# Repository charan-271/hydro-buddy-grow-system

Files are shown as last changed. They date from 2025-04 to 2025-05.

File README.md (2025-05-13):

# HydroBuddy Grow System

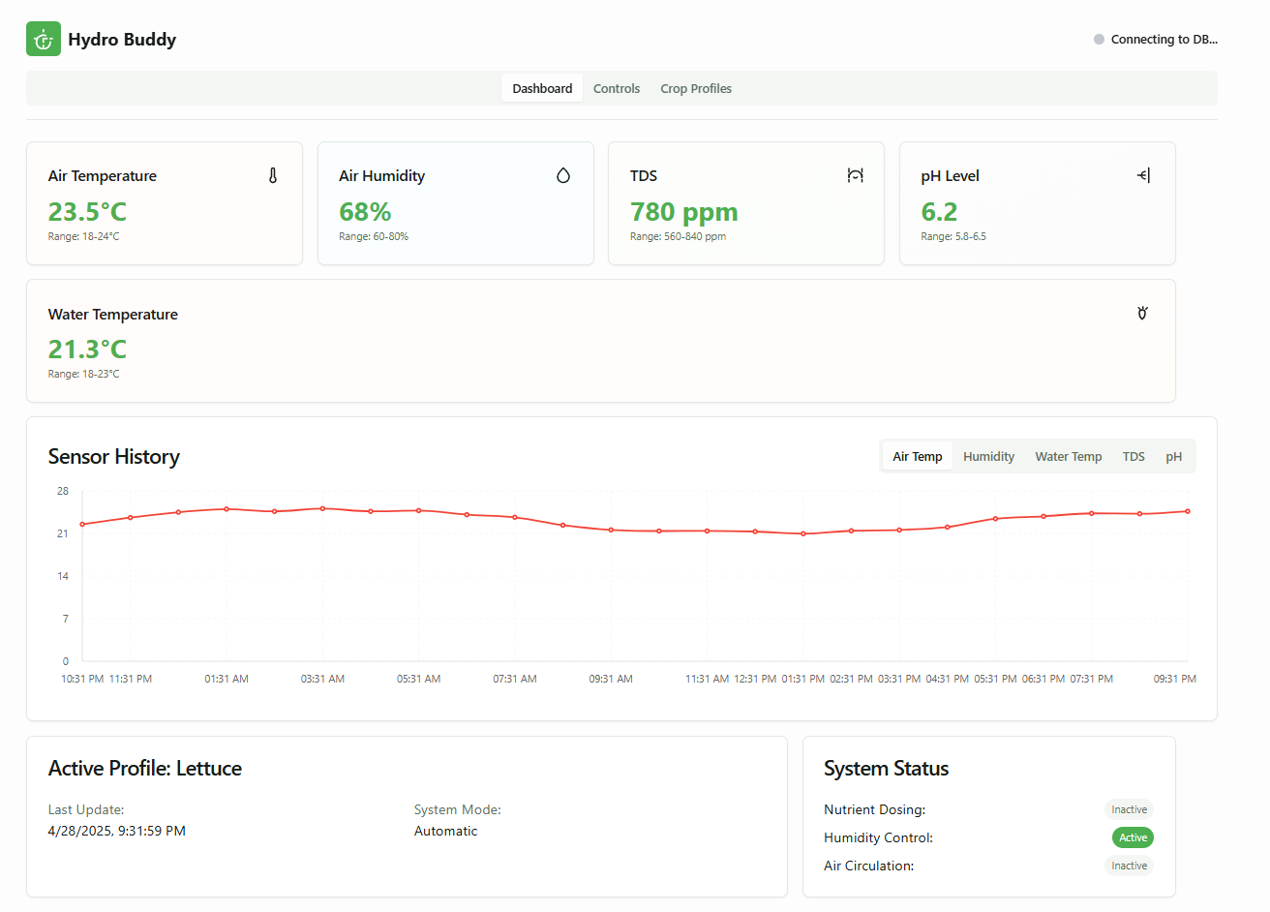
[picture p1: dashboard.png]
HydroBuddy Dashboard

*Dashboard view showing real-time sensor readings, historical data chart, and system status with relay indicators.*

HydroBuddy is a smart hydroponics monitoring and control system that helps you grow plants efficiently using IoT technology. It combines hardware sensors with a web-based dashboard to automate and monitor your hydroponic setup.

## What It Does

HydroBuddy continuously monitors key parameters for hydroponics:
- Water and air temperature
- Water pH level
- TDS (Total Dissolved Solids) for nutrient concentration
- Air humidity

The system provides:
- Real-time sensor readings
- Automated control based on crop profiles
- Historical data visualization
- Remote monitoring via web dashboard

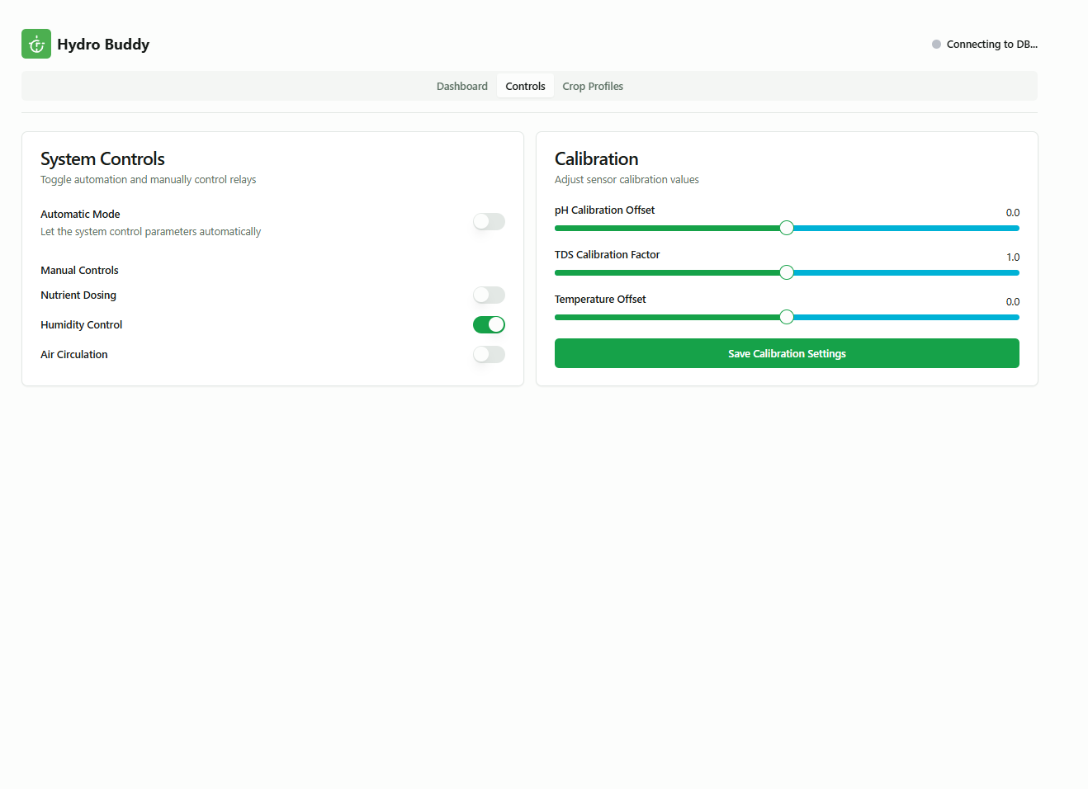
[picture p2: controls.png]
System Controls

*Control panel interface with manual relay controls, auto mode toggle, and sensor calibration settings.*

## Hardware Components

### Sensors
- DS18B20 waterproof temperature sensor (water temperature)
- DHT11 sensor (air temperature and humidity)
- Analog pH sensor with BNC connector
- TDS (EC) sensor for nutrient concentration

### Control Hardware
- ESP32 microcontroller (main board)
- BC547 transistors for relay control
- 5V relay modules for controlling pumps/fans
- Power supply (5V/2A recommended)

### Optional Components
- Peristaltic pumps for nutrient dosing
- Cooling fans for temperature control
- Humidifier for humidity control

### 3D Printed Components
The system includes 3D printable enclosures found in the STL Files directory:
- `hydroponics_box.stl` - Main enclosure for electronics
- `hydroponics_lid.stl` - Protective lid for the enclosure

### Hardware Connections

#### ESP32 Pin Connections
| Component | ESP32 Pin | Notes |
|---|---|---|
| DS18B20 Temperature Sensor | GPIO 4 | Use a 4.7kΩ pull-up resistor between data and VCC |
| DHT11 Temp/Humidity Sensor | GPIO 2 | Use a 10kΩ pull-up resistor between data and VCC |
| pH Sensor (Analog) | GPIO 34 | Analog input only, no pull-up needed |
| TDS Sensor (Analog) | GPIO 35 | Analog input only, no pull-up needed |
| Relay 1 (Nutrient Pump) | GPIO 25 | Via BC547 transistor with 1kΩ base resistor |
| Relay 2 (pH Control) | GPIO 26 | Via BC547 transistor with 1kΩ base resistor |
| Relay 3 (Water Pump) | GPIO 27 | Via BC547 transistor with 1kΩ base resistor |
| Relay 4 (Fan/Cooling) | GPIO 14 | Via BC547 transistor with 1kΩ base resistor |

#### Power Connections
- ESP32: 5V from power supply or USB
- Sensors: 3.3V from ESP32 or regulated 3.3V supply
- Relays: 5V from external power supply (separate from ESP32 logic power)

#### Transistor Wiring (for each relay)
```
ESP32 GPIO Pin ---> 1kΩ Resistor ---> BC547 Base
                                       BC547 Emitter ---> GND
                                       BC547 Collector ---> Relay Control Pin
```

#### Sensor Wiring
- **DS18B20 Temperature Sensor**:
  - Red wire to 3.3V
  - Black wire to GND
  - Yellow/Data wire to GPIO 4 with 4.7kΩ pull-up resistor

- **DHT11 Temperature/Humidity Sensor**:
  - VCC to 3.3V
  - GND to GND
  - DATA to GPIO 2 with 10kΩ pull-up resistor

- **pH Sensor**:
  - BNC connector to pH probe
  - VCC to 5V
  - GND to GND
  - Analog Output to GPIO 34

- **TDS Sensor**:
  - VCC to 5V
  - GND to GND
  - Analog Output to GPIO 35

### Wiring Diagram Notes
- Keep sensor cables away from power lines to reduce interference
- Use shielded cables for pH and TDS sensors to improve accuracy
- Add 100μF capacitor between relay power supply and GND to reduce interference
- Connect all GND points to a common ground

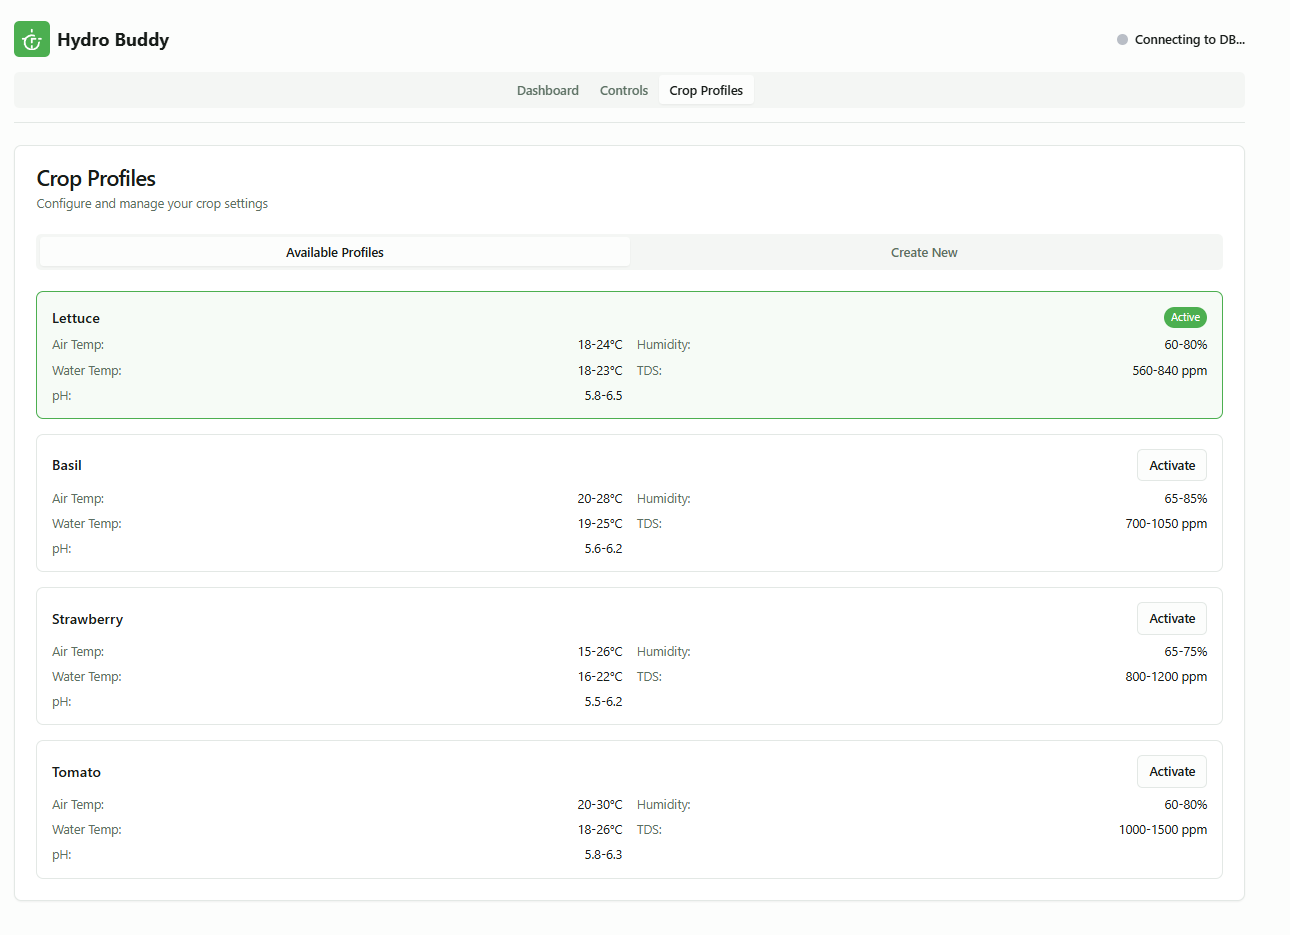
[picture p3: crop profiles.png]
Crop Profiles Management

*Crop profiles management interface showing parameter ranges for different crops and profile activation controls.*

## Software Components

### Microcontroller Code
- Arduino code for ESP32 (`hydroponics_final.ino`)
- Sensor data collection and processing
- WiFi connectivity and HTTP server
- Automatic control logic based on crop parameters

### Web Dashboard
- React TypeScript frontend
- Realtime sensor data visualization with interactive charts
- Crop profile management
- Responsive design for desktop/mobile access

### Backend
- Supabase for data storage and authentication
- RESTful API endpoints for sensor data
- Serverless functions for relay control and data processing
- Historical data retrieval and analysis

## Setting Up the Project

### Hardware Setup
1. Connect sensors to the ESP32 according to the pin definitions in `hydroponics_final/hydroponics_final.ino`
2. Connect the relay modules to the transistor control pins
3. Power the ESP32 and sensors with a 5V power supply
4. Optional: 3D print the enclosure using the STL files provided

### Software Setup
1. Clone the repository:
   ```
   git clone https://github.com/charan-271/hydro-buddy-grow-system.git
   cd hydro-buddy-grow-system
   ```

2. Install dependencies:
   ```
   bun install
   ```

3. Configure the ESP32:
   - Open `hydroponics_final/hydroponics_final.ino` in Arduino IDE
   - Set your WiFi credentials
   - Set the correct API endpoint for your Supabase instance
   - Upload to your ESP32

4. Configure the web dashboard:
   - Create a `.env` file with your Supabase credentials
   - Start the development server:
     ```
     bun run dev
     ```

5. Deploy Supabase functions:
   ```
   cd supabase
   supabase functions deploy
   ```

## Project Structure
The project follows a clean and modular structure:
- `/src/components` - React components for the dashboard
- `/src/hooks` - Custom React hooks for data and WebSocket handling
- `/src/integrations/supabase` - Supabase client configuration
- `/supabase/functions` - Serverless functions for relay and sensor data
- `/hydroponics_final` - Arduino code for the ESP32
- `/STL Files` - 3D printable enclosure designs

## Main Features

- **Real-time Monitoring**: View sensor data as it's collected
- **Historical Data**: Track plant growth conditions over time
- **Crop Profiles**: Preset configurations for different plant types
- **Automated Control**: Set-and-forget system that adjusts to optimal conditions
- **Mobile Responsive**: Monitor your system from anywhere

## Technologies Used

- **Frontend**: React, TypeScript, TailwindCSS, Shadcn UI
- **Backend**: Supabase (PostgreSQL database)
- **Hardware**: ESP32, Arduino libraries
- **Communication**: HTTP for API requests, WebSockets for realtime updates
- **Build Tools**: Vite, Bun

## Contributing

Contributions are welcome! Please feel free to submit a Pull Request.

## License

This project is open-source, available under the MIT License.

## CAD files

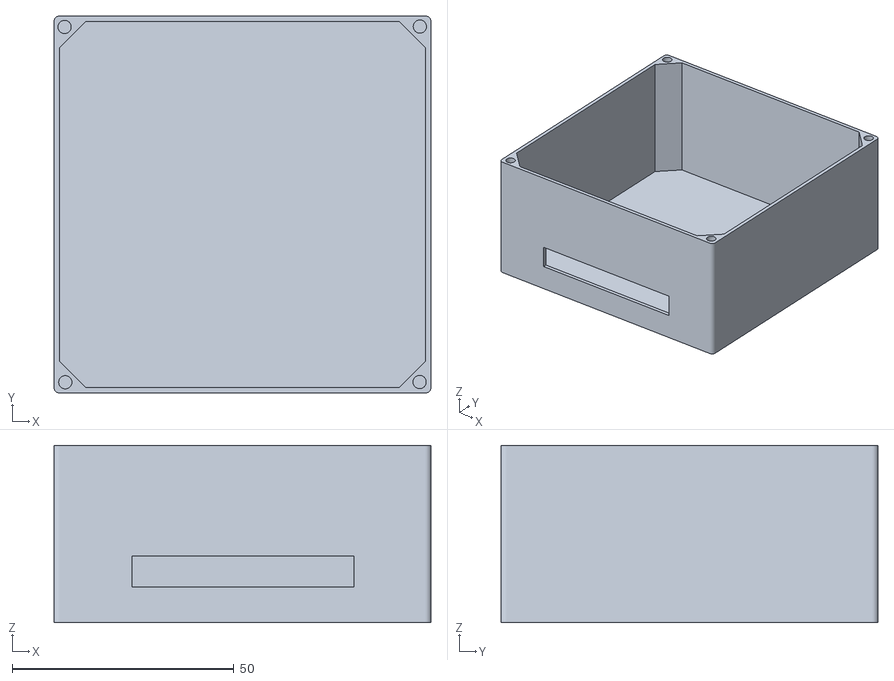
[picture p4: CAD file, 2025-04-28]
STL Files/hydroponics_box.stl
85.0 x 85.0 x 40.0

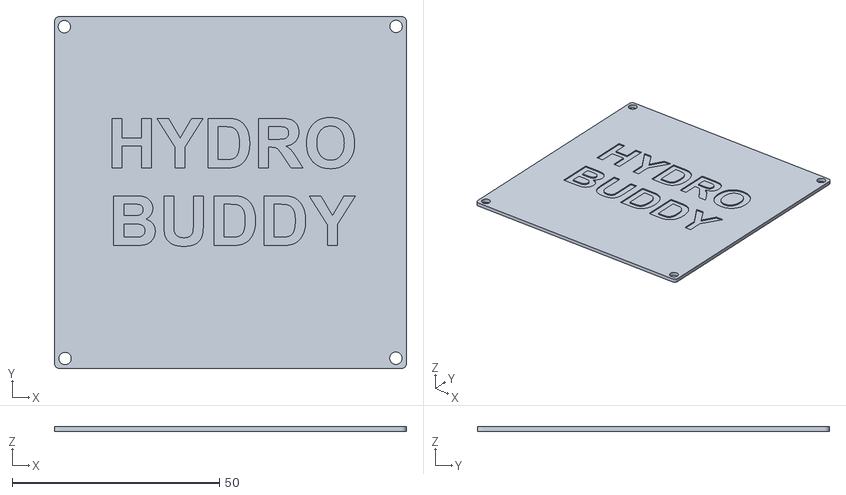
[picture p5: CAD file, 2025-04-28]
STL Files/hydroponics_lid.stl
85.0 x 85.0 x 1.20

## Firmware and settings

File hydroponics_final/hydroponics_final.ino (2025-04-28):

#include <WiFi.h>
#include <WebServer.h>
#include <HTTPClient.h>
#include <ArduinoJson.h>
#include <DHT.h>
#include <OneWire.h>
#include <DallasTemperature.h>

// WiFi Credentials
const char* ssid = "";
const char* password = "";

// Supabase Edge Function URL 
const char* serverUrl = "https://lstmfefngokizyxqpbdo.supabase.co/functions/v1/add-sensor-reading";

// Create Web Server on port 80
WebServer server(80);

// Pin Definitions
#define DHTPIN 4          // DHT11 data pin
#define DHTTYPE DHT11     // DHT 11
#define TDS_SENSOR_PIN 34 // Analog pin for TDS sensor
#define PH_SENSOR_PIN 32  // Analog pin for pH sensor
#define ONE_WIRE_BUS 22   // DS18B20 data pin (water temperature)

// Transistor Control Pins (BC547)
#define TRANSISTOR_WATER 17 // BC547 transistor for humidity control
#define TRANSISTOR_AIR 19   // BC547 transistor for air temperature control

// Sensor objects
DHT dht(DHTPIN, DHTTYPE);
OneWire oneWire(ONE_WIRE_BUS);
DallasTemperature waterTempSensor(&oneWire);

// Sensor calibration values
#define TDS_VREF 5.0      // Analog reference voltage
#define TDS_TEMPERATURE 25 // Reference temperature for TDS readings
float phCalibration = 0.0; // pH calibration offset

// Sensor Data Variables
float tdsValue = 0.0;
float pHValue = 0.0;
float humidity = 0.0;
float waterTemp = 0.0;
float airTemp = 0.0;

// Crop Configuration Structure
struct CropConfig {
  float min_tds = 0.0, max_tds = 0.0;
  float min_ph = 0.0, max_ph = 0.0;
  float min_humidity = 0.0, max_humidity = 0.0;
  float min_water_temp = 0.0, max_water_temp = 0.0;
  float min_air_temp = 0.0, max_air_temp = 0.0;
} cropConfig;

// Timing for non-blocking loop
unsigned long lastCheck = 0;
const unsigned long checkInterval = 10000; // 10 seconds
unsigned long lastSensorRead = 0;
const unsigned long sensorReadInterval = 2000; // 2 seconds
unsigned long lastDataUpload = 0;
const unsigned long dataUploadInterval = 10000; // 1 minute

// Utility: Check if cropConfig is actually configured
bool isCropConfigured() {
  return cropConfig.max_tds > 0.0 || cropConfig.max_ph > 0.0 ||
         cropConfig.max_humidity > 0.0 || cropConfig.max_water_temp > 0.0 ||
         cropConfig.max_air_temp > 0.0;
}

// Read TDS Sensor Value
float readTDSSensor() {
  // Read analog value and convert to voltage
  int analogValue = analogRead(TDS_SENSOR_PIN);
  float voltage = analogValue * (TDS_VREF / 4095.0); // ESP32 ADC is 12-bit (0-4095)
  
  // Temperature compensation
  float compensationCoefficient = 1.0 + 0.02 * (waterTemp - TDS_TEMPERATURE);
  float compensationVoltage = voltage / compensationCoefficient;
  
  // Convert voltage to TDS value
  float tdsValue = (133.42 * compensationVoltage * compensationVoltage * compensationVoltage 
                   - 255.86 * compensationVoltage * compensationVoltage 
                   + 857.39 * compensationVoltage) * 0.5;
  
  return tdsValue;
}

// Read pH Sensor Value
float readPHSensor() {
  // Get multiple samples for more accurate reading
  int samples = 10;
  float avgValue = 0;
  
  for(int i=0; i<samples; i++) {
    avgValue += analogRead(PH_SENSOR_PIN);
    delay(10);
  }
  
  avgValue = avgValue / samples;
  
  // Convert analog reading to voltage
  float voltage = avgValue * (3.3 / 4095.0); // ESP32 ADC is 12-bit (0-4095)
  float phValue = 3.5 * voltage + phCalibration;
  
  return phValue;
}

// Read all sensors
void readSensors() {
  // Read DHT11 (air temperature and humidity)
  humidity = dht.readHumidity();
  airTemp = dht.readTemperature();
  
  // Check if DHT reading failed
  if (isnan(humidity) || isnan(airTemp)) {
    Serial.println("❌ Failed to read from DHT sensor!");
    humidity = 0.0;
    airTemp = 0.0;
  }
  
  // Read DS18B20 water temperature
  waterTempSensor.requestTemperatures();
  waterTemp = waterTempSensor.getTempCByIndex(0);
  
  // Check if water temperature reading failed
  if (waterTemp == DEVICE_DISCONNECTED_C) {
    Serial.println("❌ Failed to read from DS18B20 sensor!");
    waterTemp = 0.0;
  }
  
  // Read TDS value
  tdsValue = readTDSSensor();
  
  // Read pH value
  pHValue = readPHSensor();
  
  // Log values
  Serial.println("📊 Sensor Readings:");
  Serial.print("TDS: "); Serial.print(tdsValue); Serial.println(" ppm");
  Serial.print("pH: "); Serial.println(pHValue);
  Serial.print("Humidity: "); Serial.print(humidity); Serial.println(" %");
  Serial.print("Water Temp: "); Serial.print(waterTemp); Serial.println(" °C");
  Serial.print("Air Temp: "); Serial.print(airTemp); Serial.println(" °C");
}

// Send sensor data to database via API
void sendSensorData() {
  if (WiFi.status() == WL_CONNECTED) {
    Serial.println("📤 Sending data to database...");
    HTTPClient http;
    
    // Create a JSON document
    StaticJsonDocument<200> doc;
    doc["air_temp"] = airTemp;
    doc["water_temp"] = waterTemp;
    doc["humidity"] = humidity;
    doc["ph"] = pHValue;
    doc["tds"] = tdsValue;
    
    String jsonString;
    serializeJson(doc, jsonString);
    
    // Begin HTTP POST request
    http.begin(serverUrl);
    http.addHeader("Content-Type", "application/json");
    
    // Send HTTP POST request
    int httpResponseCode = http.POST(jsonString);
    
    if (httpResponseCode > 0) {
      String response = http.getString();
      Serial.println("✅ HTTP Response code: " + String(httpResponseCode));
      Serial.println(response);
    } else {
      Serial.print("❌ Error code: ");
      Serial.println(httpResponseCode);
    }
    
    // Free resources
    http.end();
  } else {
    Serial.println("❌ WiFi disconnected. Cannot send data.");
  }
}

// Handle Root
void handleRoot() {
  server.send(200, "text/plain", "ESP32 Hydroponics System");
}

// Handle Update Crop Configuration
void handleUpdate() {
  if (server.hasArg("plain")) {
    String jsonData = server.arg("plain");
    Serial.println("✅ Data Received!");
    Serial.println(jsonData);

    StaticJsonDocument<512> doc;
    DeserializationError error = deserializeJson(doc, jsonData);

    if (error) {
      Serial.println("❌ JSON Parsing failed!");
      server.send(400, "application/json", "{\"error\":\"Invalid JSON!\"}");
      return;
    }

    // ✅ Store values properly
    cropConfig.min_tds = doc["min_tds"] | 0.0;
    cropConfig.max_tds = doc["max_tds"] | 0.0;
    cropConfig.min_ph = doc["min_ph"] | 0.0;
    cropConfig.max_ph = doc["max_ph"] | 0.0;
    cropConfig.min_humidity = doc["min_humidity"] | 0.0;
    cropConfig.max_humidity = doc["max_humidity"] | 0.0;
    cropConfig.min_water_temp = doc["min_water_temp"] | 0.0;
    cropConfig.max_water_temp = doc["max_water_temp"] | 0.0;
    cropConfig.min_air_temp = doc["min_atmosphere_temp"] | 0.0;
    cropConfig.max_air_temp = doc["max_atmosphere_temp"] | 0.0;

    Serial.println("✅ Crop configuration updated!");
    Serial.print("min_tds: "); Serial.println(cropConfig.min_tds);
    Serial.print("max_tds: "); Serial.println(cropConfig.max_tds);

    server.send(200, "application/json", "{\"message\":\"Configuration updated successfully!\"}");
  } else {
    server.send(400, "application/json", "{\"error\":\"Invalid data!\"}");
  }
}

// Handle Sensor Data Response
void handleSensorData() {
  server.sendHeader("Access-Control-Allow-Origin", "*");
  server.sendHeader("Access-Control-Allow-Methods", "GET, POST, OPTIONS");
  server.sendHeader("Access-Control-Allow-Headers", "Content-Type");
  
  // Create a proper JSON document
  StaticJsonDocument<256> doc;
  doc["status"] = "connected";
  doc["isConfigured"] = isCropConfigured();
  doc["TDS"] = tdsValue;
  doc["pH"] = pHValue;
  doc["Humidity"] = humidity;
  doc["WaterTemp"] = waterTemp;
  doc["AirTemp"] = airTemp;
  
  String jsonResponse;
  serializeJson(doc, jsonResponse);
  server.send(200, "application/json", jsonResponse);
}

// Optional Status Check Endpoint
void handleStatus() {
  String status = isCropConfigured() ? "✅ Crop data configured" : "⚠️ No crop data";
  server.send(200, "application/json", "{\"status\":\"" + status + "\"}");
}

// CORS handling
void handleOptions() {
  server.sendHeader("Access-Control-Allow-Origin", "*");
  server.sendHeader("Access-Control-Allow-Methods", "GET, POST, OPTIONS");
  server.sendHeader("Access-Control-Allow-Headers", "Content-Type");
  server.send(204);
}

// Control function for transistors
void controlTransistor(int pin, bool turnOn) {
  // For BC547 transistor, we send HIGH to turn ON and LOW to turn OFF
  // This is because the transistor conducts when base is HIGH
  digitalWrite(pin, turnOn ? HIGH : LOW);
  
  // Log the action
  Serial.print("Transistor on pin ");
  Serial.print(pin);
  Serial.println(turnOn ? " turned ON" : " turned OFF");
}

// Core Logic to Check Ranges
void checkAndControl() {
  if (!isCropConfigured()) {
    Serial.println("⚠️ No crop data configured!");
    return;
  }

  Serial.println("✅ Running automated control checks");

  if (tdsValue > cropConfig.max_tds) {
    Serial.println("⚠️ TDS out of range!");
  } else {
    Serial.println("✅ TDS is in range");
  }
  
  if (pHValue > cropConfig.max_ph) {
    Serial.println("⚠️ pH out of range!");
    // Add pH control transistor here if needed
  } else {
    Serial.println("✅ pH is in range");
  }

  if (humidity > cropConfig.max_humidity) {
    Serial.println("⚠️ Humidity out of range!");
  } else {
    Serial.println("✅ Humidity is in range!");
  }
  
  if (waterTemp > cropConfig.max_water_temp) {
    Serial.println("⚠️ Water Temperature out of range!");
    controlTransistor(TRANSISTOR_WATER, true);
  } else {
    Serial.println("✅ Water Temperature is in range!");
    controlTransistor(TRANSISTOR_WATER, false);
  }
  
  if (airTemp > cropConfig.max_air_temp) {
    Serial.println("⚠️ Air Temperature out of range!");
    controlTransistor(TRANSISTOR_AIR, true); // Turn ON fan
  } else {
    Serial.println("✅ Air Temperature is in range!");
    controlTransistor(TRANSISTOR_AIR, false); // Turn OFF fan
  }
}

// WiFi Setup
void connectToWiFi() {
  WiFi.begin(ssid, password);
  Serial.print("⏳ Connecting to WiFi");
  int attempts = 0;
  while (WiFi.status() != WL_CONNECTED && attempts < 20) {
    delay(500);
    Serial.print(".");
    attempts++;
  }

  if (WiFi.status() == WL_CONNECTED) {
    Serial.println("\n✅ Connected to WiFi!");
    Serial.print("📡 IP Address: ");
    Serial.println(WiFi.localIP());
  } else {
    Serial.println("\n❌ Failed to connect. Restarting...");
    ESP.restart();
  }
}

// Setup Function
void setup() {
  Serial.begin(115200);
  
  // Initialize sensors
  dht.begin();
  waterTempSensor.begin();
  
  // Initialize transistor control pins
  pinMode(TRANSISTOR_WATER, OUTPUT);
  pinMode(TRANSISTOR_AIR, OUTPUT);
  
  // Set initial state to OFF
  digitalWrite(TRANSISTOR_WATER, LOW);
  digitalWrite(TRANSISTOR_AIR, LOW);
  
  // Connect to WiFi
  connectToWiFi();

  // Define Routes
  server.on("/", HTTP_GET, handleRoot);
  server.on("/update", HTTP_POST, handleUpdate);
  server.on("/sensor-data", HTTP_GET, handleSensorData);
  server.on("/status", HTTP_GET, handleStatus);
  server.onNotFound([]() {
    if (server.method() == HTTP_OPTIONS) {
      handleOptions();
    } else {
      server.send(404, "text/plain", "Not found");
    }
  });

  server.begin();
  Serial.println("🌍 Server started!");
  
  // Initial sensor reading
  readSensors();
}

// Main Loop
void loop() {
  server.handleClient();

  unsigned long currentMillis = millis();
  
  // Read sensors at regular intervals
  if (currentMillis - lastSensorRead >= sensorReadInterval) {
    lastSensorRead = currentMillis;
    readSensors();
  }
  
  // Check and control at regular intervals
  if (currentMillis - lastCheck >= checkInterval) {
    lastCheck = currentMillis;
    checkAndControl();
  }
  
  // Send data to database at regular intervals
  if (currentMillis - lastDataUpload >= dataUploadInterval) {
    lastDataUpload = currentMillis;
    sendSensorData();
  }
  
  // Check if WiFi is connected and reconnect if needed
  if (WiFi.status() != WL_CONNECTED) {
    Serial.println("WiFi disconnected. Attempting to reconnect...");
    connectToWiFi();
  }
}

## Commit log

2025-04-06 Add hydroponics system
    Implement an automated hydroponics monitoring and control system using an ESP32 microcontroller, sensors (DHT11, DS18B20, TDS, pH), relays, and a web interface for remote monitoring and configuration.
2025-04-06 Add realtime sensor data
    Implement realtime sensor data updates.
2025-04-06 feat: Integrate API for sensor data
    Implement API calls to send and fetch sensor data from a database.
2025-04-06 Reverted to edit edt-37c0b5d9-2dbc-4562-a8ac-b9c146506a9d: "Add realtime sensor data
    Implement realtime sensor data updates."
2025-04-06 Add database integration
    Integrate a database to store sensor data.
